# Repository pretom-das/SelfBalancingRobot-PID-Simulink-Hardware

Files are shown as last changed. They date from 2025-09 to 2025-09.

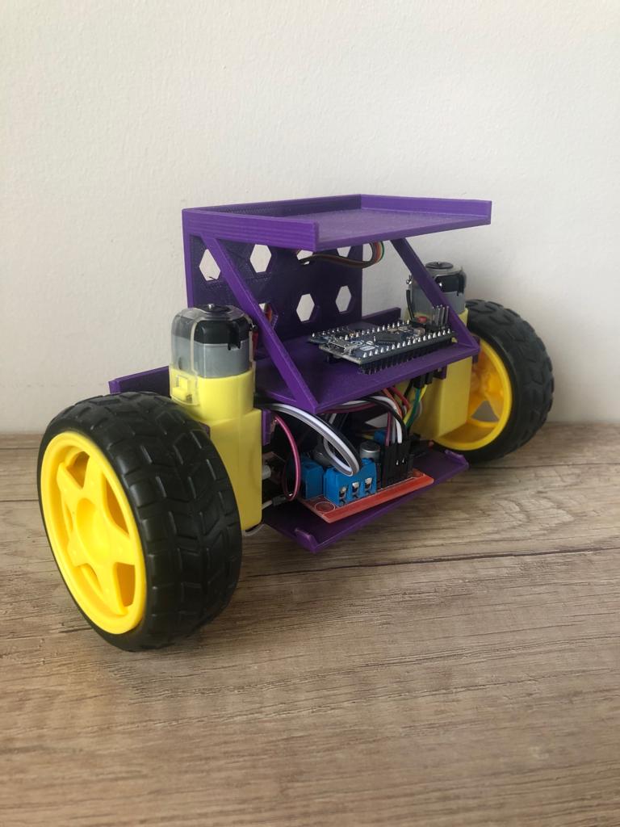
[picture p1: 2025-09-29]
3D print/images/WhatsApp_Image_2019-05-04_at_4.56.32_PM.jpeg

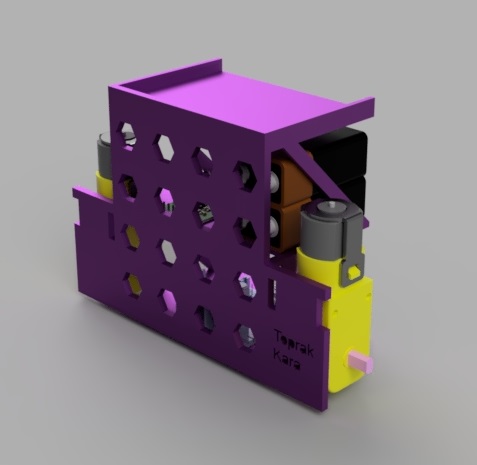
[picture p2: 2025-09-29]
3D print/images/render_back.jpg

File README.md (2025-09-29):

# PID Controlled Self-Balancing Robot

This repository contains all resources for the project:

**"PID Controlled Self-Balancing Robot using MATLAB Simulink and Hardware Implementation: Evaluating Performance under Disturbance"**

---

## 📂 Folder Structure
- `3d-print/` – STL files for chassis, wheels, and mounts.
- `hardware/` – Arduino code for MPU6050, PID controller, motor driver, and OLED HUD.
- `Simulink/` – MATLAB Simulink models and simulation results.
- `papers/` – Research paper (LaTeX + figures).

---

## 🚀 Features
- Real-time balancing using MPU6050 DMP.
- PID controller designed in MATLAB Simulink and validated in hardware.
- OLED HUD for live visualization of angles, PID output, and setpoint.
- STL files for custom 3D-printed chassis and parts.
- Disturbance performance evaluation (push tests, uneven surface, etc.).

---

## 🛠️ Requirements
- MATLAB/Simulink R2021a or later
- Arduino IDE
- MPU6050, L298N, DC motors, SH1106 OLED
- 3D printer for mechanical parts

---

## 📊 Results
- Successfully balanced robot under controlled disturbances.
- Simulink and hardware results compared for validation.

---

---

## Bill of Materials

* Arduino **UNO** (or Nano with same pins)
* **MPU6050** 6-axis IMU (I²C)
* **SH1106** 1.3″ 128×64 OLED (I²C, 0x3C default)
* **L298N** dual H-bridge motor driver
* 2× DC gear motors (left/right)
* Battery pack (recommended **2S Li-ion/LiPo 7.4 V** or **6×AA NiMH 7.2 V**)
* 100–470 µF electrolytic capacitor (across motor supply near L298N)
* Slide switch (battery power)
* Wires, breadboard/headers

> **Power rule:** share **common GND** between UNO, L298N, MPU6050, OLED.

---

## ⚡ Wiring & Power

### I²C Devices (MPU6050 + SH1106 OLED)

| Function  | MPU6050 | SH1106 OLED | UNO Pin |
| --- | --- | --- | --- |
| Power | VCC (3.3–5 V)* | VCC (3.3–5 V)* | **5V** (or 3.3V if required) |
| Ground | GND | GND | **GND** |
| I²C Clock | SCL | SCL | **A5 (SCL)** |
| I²C Data  | SDA | SDA | **A4 (SDA)** |

*Most breakout boards are 5 V-tolerant on I²C; check yours.*

**I²C addresses:**
- MPU6050: `0x68` (AD0=LOW) or `0x69` (AD0=HIGH)
- SH1106: `0x3C` (your sketch uses this)

---

### Motor Driver (L298N) ↔ Arduino

* `ENA → D5 (PWM)`
* `IN1 → D7`, `IN2 → D8`
* `ENB → D6 (PWM)`
* `IN3 → D12`, `IN4 → D13`

| L298N Pin | Connect to |
| --- | --- |
| **ENA** | UNO **D5** (PWM) |
| **IN1** | UNO **D7** |
| **IN2** | UNO **D8** |
| **IN3** | UNO **D12** |
| **IN4** | UNO **D13** |
| **ENB** | UNO **D6** (PWM) |
| **OUT1/OUT2** | Left motor terminals |
| **OUT3/OUT4** | Right motor terminals |
| **12V (V_s)** | Battery **+** (motor supply) |
| **GND** | Battery **−** **and** UNO **GND** (common ground) |
| **5V (on L298N)** | **Do NOT** feed UNO from here. Leave unconnected or remove jumper if present. |

---

### Powering the System

- **UNO logic:** from USB (development) or a 5 V buck converter from the battery.  
- **Motors:** battery → L298N **12V (V_s)**.  
- **Grounds:** UNO **GND** ↔ L298N **GND** ↔ battery **−** ↔ sensor GND.  

**Decoupling:** add a **100–470 µF** electrolytic across **V_s–GND** near the L298N.

## 📄 License
This project is licensed under the MIT License.

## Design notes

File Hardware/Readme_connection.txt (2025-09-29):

Here’s a **ready-to-paste README wiring section** for your self-balancing robot (UNO + MPU6050 + SH1106 + L298N). It matches the pin names in your sketch.

# Wiring & Power

## Bill of Materials

* Arduino **UNO** (or Nano with same pins)
* **MPU6050** 6-axis IMU (I²C)
* **SH1106** 1.3″ 128×64 OLED (I²C, 0x3C default)
* **L298N** dual H-bridge motor driver
* 2× DC gear motors (left/right)
* Battery pack (recommended **2S Li-ion/LiPo 7.4 V** or **6×AA NiMH 7.2 V**)
* 100–470 µF electrolytic cap across motor supply (near L298N)
* Slide switch (battery power)
* Wires, breadboard/headers

> **Power rule:** share **common GND** between UNO, L298N, MPU6050, OLED.

---

## Pin Map (Arduino UNO)

### I²C Devices (MPU6050 + SH1106 OLED)

| Function  | MPU6050 | SH1106 OLED | UNO Pin |
| --- | --- | --- | --- |
| Power | VCC (3.3–5 V)* | VCC (3.3–5 V)* | **5V** (or 3.3V if your modules require) |
| Ground | GND | GND | **GND** |
| I²C Clock | SCL | SCL | **A5 (SCL)** |
| I²C Data  | SDA | SDA | **A4 (SDA)** |

* Most breakout boards are 5 V-tolerant on I²C; check yours. Both modules can run from 3.3 V as well, but keep **both** on the same logic level as the UNO I²C.

**I²C addresses**

* MPU6050: `0x68` (AD0=LOW) or `0x69` (AD0=HIGH)
* SH1106: `0x3C` (your sketch uses this)

---

### Motor Driver (L298N) ↔ Arduino

Your sketch uses:

* `ENA → D5 (PWM)`
* `IN1 → D7`, `IN2 → D8`
* `ENB → D6 (PWM)`
* `IN3 → D12`, `IN4 → D13`

**Connect:**

| L298N Pin | Connect to |
| --- | --- |
| **ENA** | UNO **D5** (PWM) |
| **IN1** | UNO **D7** |
| **IN2** | UNO **D8** |
| **IN3** | UNO **D12** |
| **IN4** | UNO **D13** |
| **ENB** | UNO **D6** (PWM) |
| **OUT1/OUT2** | Left motor terminals |
| **OUT3/OUT4** | Right motor terminals |
| **12V (V_s)** | Battery **+** (motor supply) |
| **GND** | Battery **−** **and** UNO **GND** (common ground) |
| **5V (on L298N)** | **Do NOT** feed UNO from here. Leave unconnected or remove 5 V jumper if present. |

> If your L298N has a **5V-EN** jumper: with **motor V_s ≥ 7 V**, the board’s regulator can power *its own* logic. Still **do not** back-power the UNO from the L298N 5 V pin.

---

### Powering the System

* **UNO logic:** from USB during development, or a clean 5 V regulator (e.g., buck converter from the battery) into **5V** pin.
  *Avoid VIN/barrel jack if your battery is only ~7–8 V; the onboard linear regulator may overheat / drop too much.*
* **Motors:** battery → L298N **12V (V_s)**.
* **Grounds:** connect UNO **GND** ↔ L298N **GND** ↔ battery **−** ↔ sensor GND.

**Decoupling:** place a **100–470 µF** electrolytic across **V_s–GND** at the L298N, plus a **0.1 µF** ceramic near each module (optional but helpful).

---

## Quick Text Schematic (overview)

```
Battery + ------- L298N 12V (V_s)
Battery - -----+-- L298N GND
               | 
               +-- UNO GND --- MPU6050 GND --- OLED GND
UNO 5V  --------- MPU6050 VCC --- OLED VCC
UNO A5 (SCL) ---- MPU6050 SCL --- OLED SCL
UNO A4 (SDA) ---- MPU6050 SDA --- OLED SDA

UNO D5 (PWM) ---- L298N ENA
UNO D7 ---------- L298N IN1
UNO D8 ---------- L298N IN2
UNO D6 (PWM) ---- L298N ENB
UNO D12 --------- L298N IN3
UNO D13 --------- L298N IN4

L298N OUT1/OUT2 -> Left Motor
L298N OUT3/OUT4 -> Right Motor
```

---

## Motor Polarity & Direction

* If wheels spin the **wrong way**, swap a motor’s **OUTx** wires **or** use the code switches:

  * `#define DRIVE_SIGN (-1)` → ensures **negative angle ⇒ wheels go backward** (as requested).
  * If the robot “pushes the fall,” flip sensor signs: `SIGN_PITCH` or `SIGN_GYRO` to `-1`.

---

## First-Power Checklist

1. **Upload code** with robot wheels lifted off the ground.
2. Open Serial Monitor @ **115200** (optional).
3. Verify OLED shows **“Calibrating…”**, then **“Auto-tuning…”** or **“BALANCING”**.
4. Nudge the chassis: angle on OLED should increase for **nose-up**.
5. If motion pushes the robot further over, flip `SIGN_PITCH` or `SIGN_GYRO` (not wiring).
6. If motors just buzz, increase `MOTOR_DEADBAND` (30→40–50) and/or `relay_h` (90→120).

---

## Common Gotchas

* **No common ground** → nothing works reliably.
* **Feeding UNO from L298N 5 V** → brownouts/reset under motor load. Use a separate 5 V regulator for the UNO.
* **Wrong I²C address** → blank OLED. Your code uses `0x3C`. Some SH1106 boards can be `0x3D`.
* **Loose Dupont leads** on ENA/ENB → no PWM control.

---

## Optional: Power Budget Tips

* L298N is lossy; with low-voltage batteries the headroom may be small. If you can, use **higher-torque gear motors** or a more efficient driver (TB6612FNG, BTS7960) later.
* Keep wires short and thick on motor supply; add the bulk cap at L298N.

---

## Testing Sequence

1. **I²C check:** run an I²C scanner; expect `0x68` (MPU) and `0x3C` (OLED).
2. **Sensor sign:** tilt forward/back and watch angle on OLED.
3. **Lifted wheel test:** in **RUN** mode, tilt the robot by hand; wheels should spin to resist.
4. **Floor test:** start near upright, be ready to catch. Use the built-in tilt cut-off (±35°).

---

Copy this into your repo’s `README.md` under a “Wiring & Power” section, and you’re set. If you want, I can add a neat wiring diagram (Fritzing-style PNG/SVG) for the same pinout.

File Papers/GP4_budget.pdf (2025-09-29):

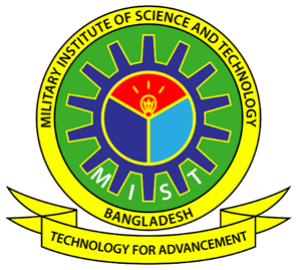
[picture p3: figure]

## Military Institute of Science and Technology

DEPARTMENT OF ELECTRICAL, ELECTRONIC AND COMMUNICATION ENGINEERING

Course Title: Control System Laboratory Course Code: EECE 402
Group: 04

### Project Report

### Robust Control of a Self-Balancing Robot: PID Implementation in MATLAB Simulink and Hardware under Disturbances

Group Information
Name | ID
Minhaj Abedin Siam | 202216063
Pretom Das | 202216072
Sabyasachi Monem | 202216077

Course Instructor:

1. Asst. Prof. Hasan Monir
2. Asst. Prof. Sunjida Sultana
3. Lec Anika Tasnim Tapti
4. Lec Lamiya Mahbub
5. Lec Zia Md Galib Ul Alim

Cost Estimation:

Component | Qty | Unit Price | Price (BDT)
Chassis (3D printed) | 1 | 400 | 400
Yellow DC Geared Motors+ wheel | 2 | 150 | 300
MPU6050 Sensor | 1 | 250 | 250
L298N Motor Driver | 1 | 180 | 180
Arduino UNO | 1 | 1000 | 1000
18650 Li-Ion Battery | 3 | 110 | 330
Battery Case (3-cell) | 1 | 60 | 60
I2C OLED Display | 1 | 680 | 680
Wires box | 1 | 200 | 200
Total | – | | 3400

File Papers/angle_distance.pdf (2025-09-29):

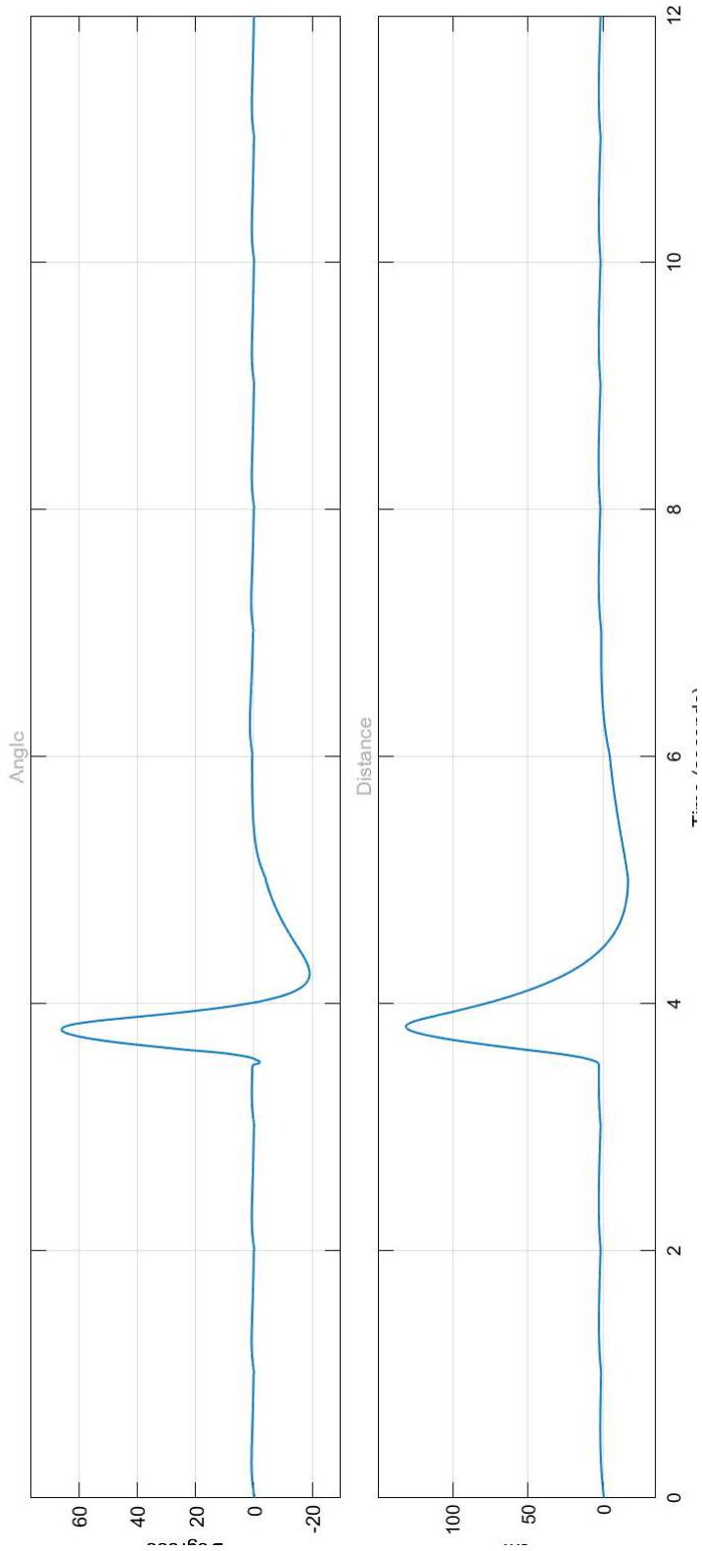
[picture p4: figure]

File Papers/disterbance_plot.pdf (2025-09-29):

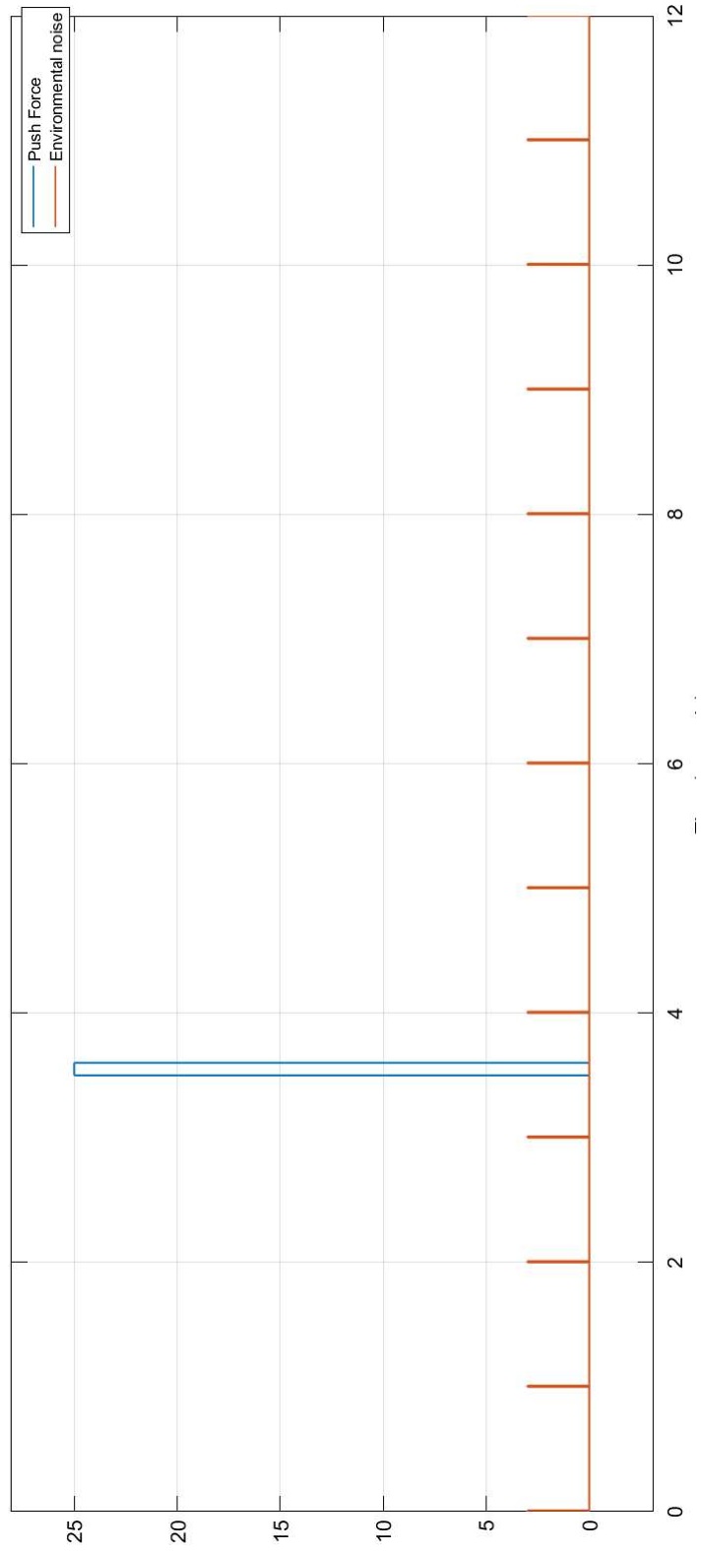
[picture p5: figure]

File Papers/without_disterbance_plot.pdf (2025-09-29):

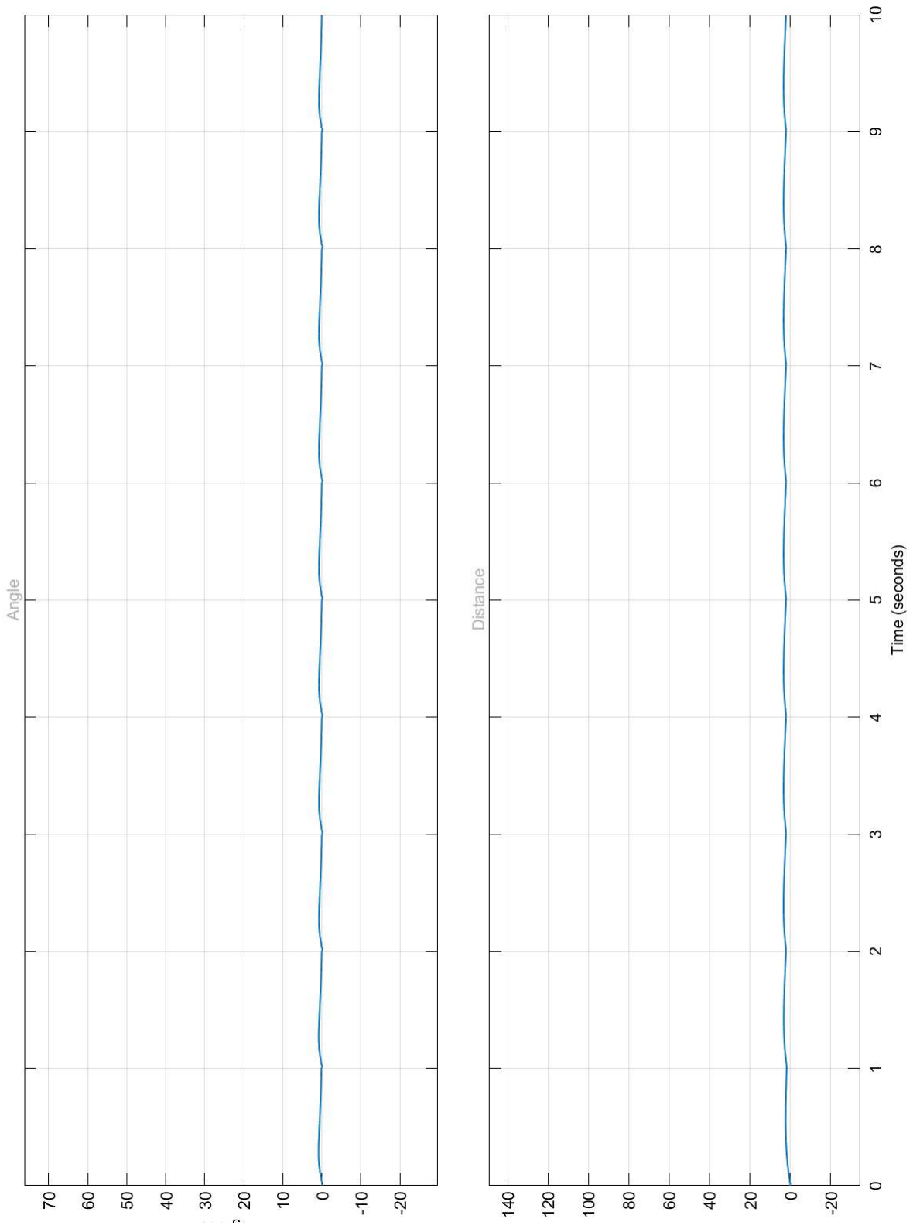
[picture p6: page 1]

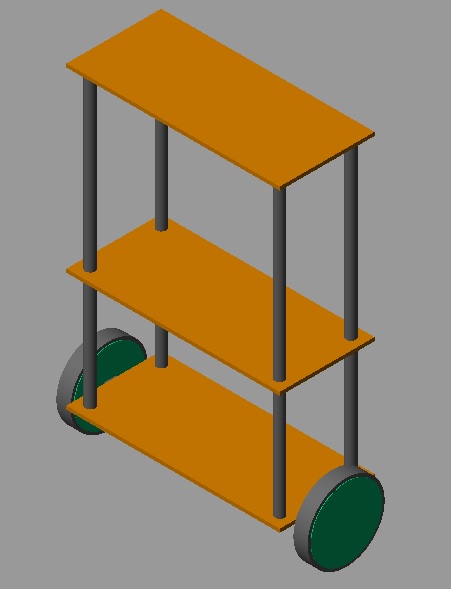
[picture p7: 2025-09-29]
Simulink/img.jpg

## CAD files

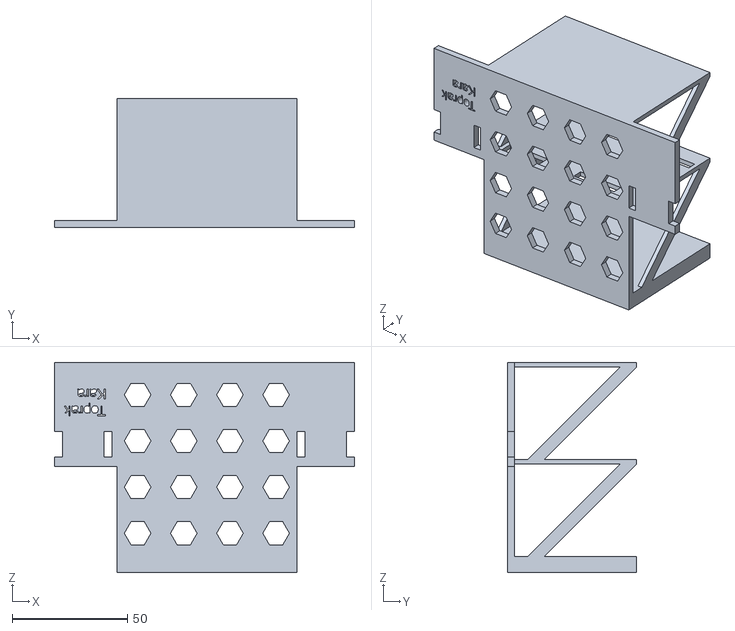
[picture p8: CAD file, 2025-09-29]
3D print/files/main_body_by_tk.stl
130.0 x 56.0 x 91.0

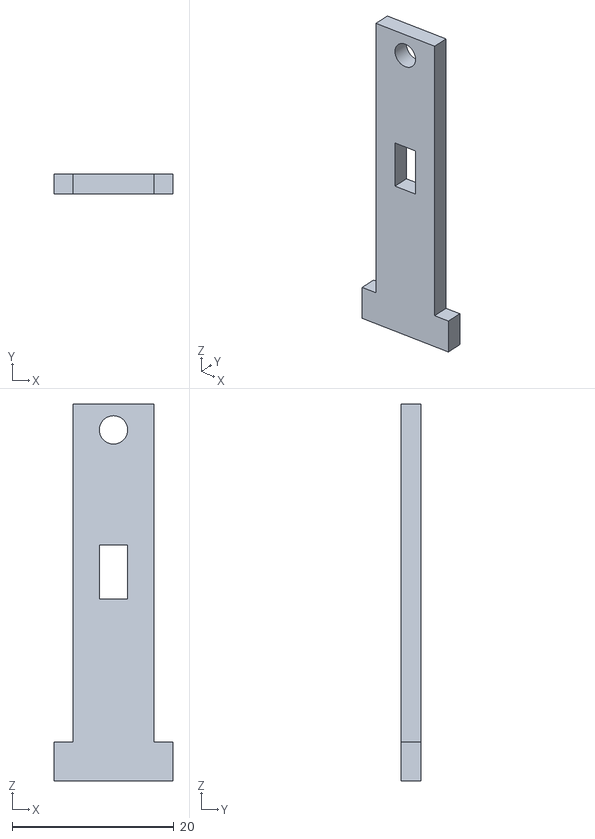
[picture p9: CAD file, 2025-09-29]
3D print/files/motor_maunt.stl
14.7 x 2.50 x 46.6

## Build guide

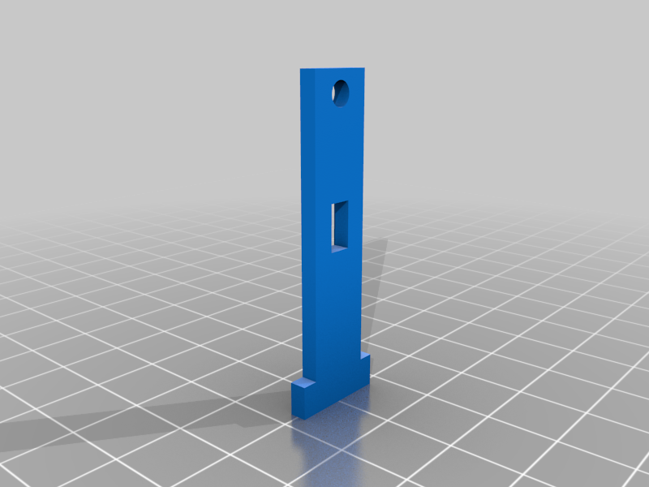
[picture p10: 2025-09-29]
3D print/images/df1292d3a46ace1f10e27a1cf0ae9d68.png

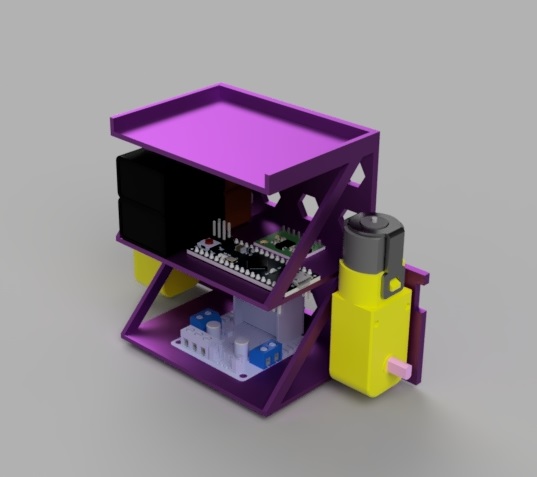
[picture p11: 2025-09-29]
3D print/images/render_1.jpg

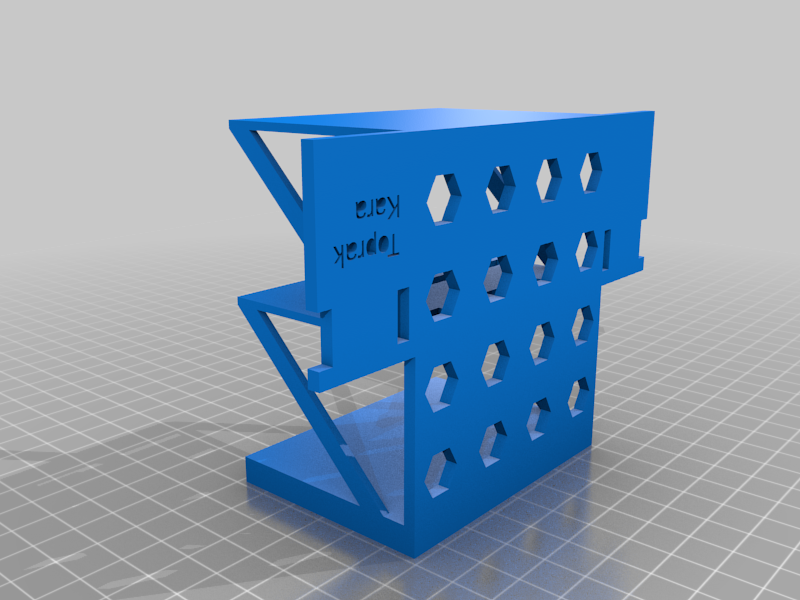
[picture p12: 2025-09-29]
3D print/images/bbad19879211f647a17827d7f1c1ca49.png

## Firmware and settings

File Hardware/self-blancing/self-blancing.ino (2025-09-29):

/*  ---------------------------------------------------------
    SELF-BALANCING ROBOT (UNO + MPU6050 + L298N + 1.3" SH1106 I2C)
    - SH1106 OLED status (I2C)
    - Complementary filter for pitch angle (gyro+accel)
    - Relay auto-tune (Åström–Hägglund) → ZN PID gains
    - EEPROM store/recall of tuned gains
    - L298N dual-motor driver
    - Fixed setpoint (SP_DEG) measured separately
    --------------------------------------------------------- */

#include <Wire.h>
#include <EEPROM.h>
#include <Adafruit_GFX.h>
#include <Adafruit_SH110X.h>
#include <math.h>

// ---------------- OLED (SH1106 128x64 I2C) ----------------
#define OLED_ADDR 0x3C
Adafruit_SH1106G display(128, 64, &Wire, -1);

// ---------------- L298N Pins ----------------
const int ENA = 5;     // PWM
const int IN1 = 7;
const int IN2 = 8;
const int ENB = 6;     // PWM
const int IN3 = 12;
const int IN4 = 13;

// ---------------- Fixed setpoint ------------
const float SP_DEG = 0.0f;  // <<< REPLACE with your measured upright angle (deg)

// ---------------- MPU6050 -------------------
const uint8_t MPU_ADDR = 0x68;   // AD0 low
const float GYRO_SENS = 131.0f;  // LSB/(°/s) @ ±250 dps
const float ACC_SENS  = 16384.0f;// LSB/g @ ±2g

float gyroX_off=0, gyroY_off=0, gyroZ_off=0;
float accX_off=0,  accY_off=0,  accZ_off=0;

// ------------- Complementary Filter ---------
float pitch_deg = 0.0f;
float alpha = 0.98f;             // gyro weight
unsigned long lastMicros = 0;
float loop_dt = 0.005f;          // seconds, updated each loop

// ---------------- PID -----------------------
volatile float setpoint = SP_DEG;     // fixed upright
float Kp = 18.0f, Ki = 0.0f, Kd = 0.6f; // defaults if no EEPROM
float i_term = 0.0f, prev_err = 0.0f;
float out_min = -255, out_max = 255;

// ------------- Auto-tune (relay) ------------
enum Mode { MODE_AUTOTUNE, MODE_RUN } mode = MODE_AUTOTUNE;
const float relay_h = 80.0f;          // PWM magnitude for relay drive (tweak 60–120)
const float tune_window = 2.0f;       // deg hysteresis around setpoint
const unsigned long settle_ms = 3000; // let oscillation stabilize
float max_angle = -1e9, min_angle = 1e9;
unsigned long last_cross_ms = 0;
unsigned long period_ms = 0;
int cross_count = 0;
bool settled = false;

// --------------- EEPROM ---------------------
struct Gains { float Kp, Ki, Kd; uint32_t magic; };
const uint32_t MAGIC = 0xBABA00F1;
const int EE_ADDR = 0;

// --------------- Utils ----------------------
float constrainf(float x, float a, float b){ return x<a? a : (x>b? b : x); }

// --------------- I2C helpers ----------------
void mpuWrite(uint8_t reg, uint8_t val){
  Wire.beginTransmission(MPU_ADDR); Wire.write(reg); Wire.write(val); Wire.endTransmission();
}
void mpuRead(uint8_t reg, uint8_t* buf, uint8_t len){
  Wire.beginTransmission(MPU_ADDR); Wire.write(reg); Wire.endTransmission(false);
  Wire.requestFrom(MPU_ADDR, len, true);
  for(uint8_t i=0;i<len && Wire.available();++i) buf[i]=Wire.read();
}

// --------------- MPU init -------------------
void mpuInit(){
  mpuWrite(0x6B, 0x00);   // PWR_MGMT_1: wake
  mpuWrite(0x1B, 0x00);   // GYRO_CONFIG: ±250 dps
  mpuWrite(0x1C, 0x00);   // ACCEL_CONFIG: ±2g
  delay(100);
}

// Keep robot still during this (~1s)
void mpuCalibrate(){
  const int N=1000;
  long gx=0, gy=0, gz=0, ax=0, ay=0, az=0;
  uint8_t raw[14];
  for(int i=0;i<N;i++){
    mpuRead(0x3B, raw, 14);
    int16_t axr = (raw[0]<<8)|raw[1];
    int16_t ayr = (raw[2]<<8)|raw[3];
    int16_t azr = (raw[4]<<8)|raw[5];
    int16_t gxr = (raw[8]<<8)|raw[9];
    int16_t gyr = (raw[10]<<8)|raw[11];
    int16_t gzr = (raw[12]<<8)|raw[13];
    ax += axr; ay += ayr; az += azr;
    gx += gxr; gy += gyr; gz += gzr;
    delay(1);
  }
  accX_off = (float)ax/N;
  accY_off = (float)ay/N;
  accZ_off = (float)az/N - ACC_SENS; // ~+1g on Z
  gyroX_off= (float)gx/N;
  gyroY_off= (float)gy/N;
  gyroZ_off= (float)gz/N;
}

// --------------- Sensor + angle -------------
void updateAngle(){
  uint8_t raw[14];
  mpuRead(0x3B, raw, 14);
  int16_t axr = (raw[0]<<8)|raw[1];
  int16_t ayr = (raw[2]<<8)|raw[3];
  int16_t azr = (raw[4]<<8)|raw[5];
  int16_t gyr = (raw[10]<<8)|raw[11];

  float axg = (axr - accX_off)/ACC_SENS;
  float ayg = (ayr - accY_off)/ACC_SENS;
  float azg = (azr - accZ_off)/ACC_SENS;

  // Pitch from accel (degrees). Assume X forward, Y left, Z up
  float accPitch = atan2f(axg, sqrtf(ayg*ayg + azg*azg)) * 180.0f/PI;
  float gyroY_dps = (gyr - gyroY_off)/GYRO_SENS;

  unsigned long now = micros();
  float dt = (lastMicros==0) ? 0.005f : (now - lastMicros)*1e-6f;
  if (dt < 0.0005f) dt = 0.0005f; // clamp to tame spikes
  if (dt > 0.02f)   dt = 0.02f;
  lastMicros = now;
  loop_dt = dt;

  // Complementary filter
  pitch_deg = alpha*(pitch_deg + gyroY_dps*dt) + (1.0f - alpha)*accPitch;
}

// --------------- Motors (L298N) -------------
void setMotorPWM(float u){
  // u in [-255, 255]
  int pwm = (int)fabs(u);
  pwm = constrain(pwm, 0, 255);

  if (u >= 0){
    // forward
    digitalWrite(IN1, HIGH); digitalWrite(IN2, LOW);
    digitalWrite(IN3, HIGH); digitalWrite(IN4, LOW);
  } else {
    // backward
    digitalWrite(IN1, LOW); digitalWrite(IN2, HIGH);
    digitalWrite(IN3, LOW); digitalWrite(IN4, HIGH);
  }

  // Overcome friction deadband
  if (pwm > 0 && pwm < 30) pwm = 30;

  analogWrite(ENA, pwm);
  analogWrite(ENB, pwm);
}

// ---------------- PID (time-based) ----------
float pidCompute(float angle){
  // continuous-time ZN gains
  static float d_filt = 0.0f;       // filtered derivative
  const float tau_d = 0.02f;         // derivative low-pass (~20 ms)
  const float dt = loop_dt;

  float err = setpoint - angle;

  // integral with anti-windup
  i_term += Ki * err * dt;
  i_term = constrainf(i_term, -300.0f, 300.0f);

  // derivative
  float derr = (err - prev_err) / (dt > 1e-6f ? dt : 1e-6f);
  float alpha_d = tau_d / (tau_d + dt);
  d_filt = alpha_d * d_filt + (1.0f - alpha_d) * derr;

  float u = Kp * err + i_term + Kd * d_filt;
  prev_err = err;
  return constrainf(u, out_min, out_max);
}

// ----- Auto-tune helpers & step function ----
void resetAutotuneState(){
  max_angle = -1e9; min_angle = 1e9;
  last_cross_ms = 0;
  period_ms = 0;
  cross_count = 0;
  settled = false;
}

bool autotuneStep(){
  float err = setpoint - pitch_deg;

  // Relay with hysteresis to avoid chatter
  static int state = 0; // -1 or +1
  if (state == 0) state = (err >= 0) ? +1 : -1;
  if (state == +1 && err < -tune_window) state = -1;
  if (state == -1 && err > +tune_window) state = +1;

  float u = (state >= 0) ? +relay_h : -relay_h;
  setMotorPWM(u);

  // Allow settling
  static unsigned long start_ms = millis();
  if (!settled && (millis() - start_ms) > settle_ms){
    settled = true;
    last_cross_ms = millis();
  }
  if (!settled) return false;

  // Track peaks within half-cycles
  if (pitch_deg > max_angle) max_angle = pitch_deg;
  if (pitch_deg < min_angle) min_angle = pitch_deg;

  // Detect state change = half-period
  static int last_state = state;
  if (state != last_state){
    unsigned long now = millis();
    unsigned long half_period = now - last_cross_ms;
    last_cross_ms = now;
    last_state = state;
    cross_count++;

    if (cross_count >= 4){ // enough samples
      period_ms = 2 * half_period; // ~full Pu
      float a = 0.5f * (max_angle - min_angle);
      if (a < 0.5f) a = 0.5f; // avoid tiny amplitude

      float Ku = (4.0f * relay_h) / (PI * a);
      float Pu = period_ms / 1000.0f;

      // Ziegler–Nichols PID (classic)
      float newKp = 0.6f * Ku;
      float newKi = 2.0f * newKp / Pu;
      float newKd = newKp * Pu / 8.0f;

      if (isfinite(newKp) && isfinite(newKi) && isfinite(newKd) &&
          newKp>0 && newKi>=0 && newKd>=0 && Pu>0.05f && Pu<5.0f){
        Kp = constrainf(newKp, 1.0f, 120.0f);
        Ki = constrainf(newKi, 0.0f, 500.0f);
        Kd = constrainf(newKd, 0.0f, 60.0f);
        Gains g{Kp,Ki,Kd,MAGIC};
        EEPROM.put(EE_ADDR, g);
        return true; // tuning done
      } else {
        // retry: reset peaks/counter
        max_angle = -1e9; min_angle = 1e9; cross_count = 0;
      }
    }
    // reset peaks for next half-cycle
    max_angle = -1e9; min_angle = 1e9;
  }
  return false;
}

// ---------------- OLED HUD ------------------
void drawOLED(const char* top){
  display.clearDisplay();
  display.setTextColor(SH110X_WHITE);

  display.setTextSize(1);
  display.setCursor(0,0);
  display.print(top);

  display.setCursor(0,14);
  display.print("Ang: "); display.print(pitch_deg,1); display.print(" deg");

  display.setCursor(0,28);
  display.print("Kp: "); display.print(Kp,1);
  display.setCursor(64,28);
  display.print("Ki: "); display.print(Ki,1);

  display.setCursor(0,42);
  display.print("Kd: "); display.print(Kd,1);

  display.setCursor(0,56);
  display.print("SP: "); display.print(setpoint,1);

  // simple balance bar
  int cx=100, cy=40, w=24, h=8;
  display.drawRect(cx, cy, w, h, SH110X_WHITE);
  float p = constrainf((pitch_deg+15.0f)/30.0f, 0.0f, 1.0f);
  int filled = (int)(p*(w-2));
  display.fillRect(cx+1, cy+1, filled, h-2, SH110X_WHITE);

  display.display();
}

// ---------------- Setup ---------------------
void setup(){
  pinMode(IN1, OUTPUT); pinMode(IN2, OUTPUT);
  pinMode(IN3, OUTPUT); pinMode(IN4, OUTPUT);
  pinMode(ENA, OUTPUT); pinMode(ENB, OUTPUT);
  analogWrite(ENA, 0); analogWrite(ENB, 0);

  Wire.begin();             // UNO: SDA=A4, SCL=A5
  Wire.setClock(100000);    // keep slow & stable
  mpuInit();

  if (!display.begin(OLED_ADDR, true)) { /* if needed, try 0x3D */ }
  display.clearDisplay(); display.display();

  // Load saved gains if present
  Gains g; EEPROM.get(EE_ADDR, g);
  if (g.magic == MAGIC && isfinite(g.Kp) && isfinite(g.Ki) && isfinite(g.Kd)){
    Kp=g.Kp; Ki=g.Ki; Kd=g.Kd; mode = MODE_RUN;
  } else {
    mode = MODE_AUTOTUNE;
  }

  drawOLED("Calibrating...");
  mpuCalibrate();           // keep robot still
  lastMicros = micros();

  Serial.begin(115200);
}

// ---------------- Loop ----------------------
void loop(){
  updateAngle();

  // Tilt safety cutout (prevents thrashing when it falls)
  if (fabs(pitch_deg) > 35.0f) {
    i_term = 0; prev_err = 0;
    setMotorPWM(0);
    drawOLED("TILT SAFETY");
    delay(10);
    return;
  }

  if (mode == MODE_AUTOTUNE){
    bool done = autotuneStep();
    drawOLED("Auto-tuning...");
    if (done){
      setMotorPWM(0);
      delay(500);
      i_term=0; prev_err=0;
      mode = MODE_RUN;
      drawOLED("Tuned & saved");
      delay(400);
    }
  } else { // MODE_RUN
    float u = pidCompute(pitch_deg);
    setMotorPWM(u);
    drawOLED("BALANCING");
  }
}

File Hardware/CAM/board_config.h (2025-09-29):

#define PWDN_GPIO_NUM     32
#define RESET_GPIO_NUM    -1
#define XCLK_GPIO_NUM     0
#define SIOD_GPIO_NUM     26
#define SIOC_GPIO_NUM     27

#define Y9_GPIO_NUM       35
#define Y8_GPIO_NUM       34
#define Y7_GPIO_NUM       39
#define Y6_GPIO_NUM       36
#define Y5_GPIO_NUM       21
#define Y4_GPIO_NUM       19
#define Y3_GPIO_NUM       18
#define Y2_GPIO_NUM       5
#define VSYNC_GPIO_NUM    25
#define HREF_GPIO_NUM     23
#define PCLK_GPIO_NUM     22

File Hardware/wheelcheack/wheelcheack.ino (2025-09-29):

/* ---------------------------------------------------------
   INTERACTIVE MOTOR JOG (UNO + L298N)
   Pins (same as your project):
     RIGHT: ENA=5 (PWM), IN1=7, IN2=8   -> OUT1/OUT2
     LEFT : ENB=6 (PWM), IN3=12, IN4=13 -> OUT3/OUT4

   Serial @ 115200. Commands (case-insensitive):
     RF [p]  -> Right  Forward  with optional PWM (0..255)
     RB [p]  -> Right  Backward
     RC      -> Right  Coast (freewheel)
     RK      -> Right  Brake (short brake)

     LF [p]  -> Left   Forward
     LB [p]  -> Left   Backward
     LC      -> Left   Coast
     LK      -> Left   Brake

     AF [p]  -> BOTH Forward
     AB [p]  -> BOTH Backward
     AC      -> BOTH Coast
     AK      -> BOTH Brake

     P [p]   -> Set default PWM (used when cmd has no [p])
     + / -   -> Increase / decrease default PWM by 10
     ?       -> Help
     X       -> All stop (brake)
   Examples:
     RF 180   (right fwd at 180)
     LB       (left back at default PWM)
     AK       (both brake)
     P 200    (set default PWM = 200)
--------------------------------------------------------- */

#include <Arduino.h>

// ---- Pins
const int ENA = 5;     // RIGHT PWM
const int IN1 = 7;
const int IN2 = 8;
const int ENB = 6;     // LEFT PWM
const int IN3 = 12;
const int IN4 = 13;

// ---- Defaults
int defaultPWM = 180;    // used if command omits [p]
int deadband   = 30;     // minimum kick to overcome friction (applied when pwm>0)

// ---- Helpers
void rightDrive(int dir, int pwm) {
  pwm = constrain(pwm, 0, 255);
  if (dir > 0)      { digitalWrite(IN1, HIGH); digitalWrite(IN2, LOW);  }
  else if (dir < 0) { digitalWrite(IN1, LOW);  digitalWrite(IN2, HIGH); }
  else              { digitalWrite(IN1, LOW);  digitalWrite(IN2, LOW);  } // coast
  if (pwm > 0 && pwm < deadband) pwm = deadband;
  analogWrite(ENA, pwm);
}
void leftDrive(int dir, int pwm) {
  pwm = constrain(pwm, 0, 255);
  if (dir > 0)      { digitalWrite(IN3, HIGH); digitalWrite(IN4, LOW);  }
  else if (dir < 0) { digitalWrite(IN3, LOW);  digitalWrite(IN4, HIGH); }
  else              { digitalWrite(IN3, LOW);  digitalWrite(IN4, LOW);  } // coast
  if (pwm > 0 && pwm < deadband) pwm = deadband;
  analogWrite(ENB, pwm);
}
void rightBrake(){ digitalWrite(IN1, HIGH); digitalWrite(IN2, HIGH); analogWrite(ENA, 0); }
void leftBrake() { digitalWrite(IN3, HIGH); digitalWrite(IN4, HIGH); analogWrite(ENB, 0); }

void allStopBrake(){ rightBrake(); leftBrake(); }
void allCoast()    { rightDrive(0,0); leftDrive(0,0); }

void printHUD(const char* msg){
  Serial.print(F("[PWM=")); Serial.print(defaultPWM);
  Serial.print(F(", dead=")); Serial.print(deadband);
  Serial.print(F("]  "));
  Serial.println(msg);
}

void help(){
  Serial.println(F("\nCommands:"));
  Serial.println(F("  RF [p], RB [p], RC, RK   -> Right motor Fwd/Back/Coast/Brake"));
  Serial.println(F("  LF [p], LB [p], LC, LK   -> Left  motor Fwd/Back/Coast/Brake"));
  Serial.println(F("  AF [p], AB [p], AC, AK   -> BOTH  motors Fwd/Back/Coast/Brake"));
  Serial.println(F("  P [p]    -> set default PWM (0..255)"));
  Serial.println(F("  + / -    -> inc/dec default PWM by 10"));
  Serial.println(F("  D [v]    -> set deadband (0..80), applied when pwm>0"));
  Serial.println(F("  X        -> ALL STOP (brake)"));
  Serial.println(F("  ?        -> this help\n"));
}

// Trim spaces and uppercase
String cleanUpper(String s){
  s.trim();
  for (unsigned i=0;i<s.length();++i) s[i] = toupper(s[i]);
  return s;
}

// Parse optional integer after a command (e.g., 'RF 180')
bool parseIntAfter(const String& s, int& outVal){
  // find first space
  int sp = s.indexOf(' ');
  if (sp < 0) return false;
  String t = s.substring(sp+1);
  t.trim();
  if (t.length()==0) return false;
  outVal = t.toInt();
  return true;
}

void setup(){
  pinMode(IN1, OUTPUT); pinMode(IN2, OUTPUT);
  pinMode(IN3, OUTPUT); pinMode(IN4, OUTPUT);
  pinMode(ENA, OUTPUT); pinMode(ENB, OUTPUT);

  allCoast();

  Serial.begin(115200);
  delay(300);
  Serial.println(F("\n=== INTERACTIVE MOTOR JOG ==="));
  Serial.println(F("Type '?' for help. Place robot on a stand!"));
  printHUD("Ready.");
}

void loop(){
  // quick +/- shortcuts without newline
  if (Serial.available()){
    // Peek: if single-char control, handle directly
    int c = Serial.peek();
    if (c=='+' || c=='-'){
      Serial.read();
      defaultPWM = constrain(defaultPWM + (c=='+'? +10 : -10), 0, 255);
      printHUD(c=='+' ? "PWM +10" : "PWM -10");
      return;
    }
  }

  if (Serial.available()){
    String line = Serial.readStringUntil('\n');
    line = cleanUpper(line);
    if (line.length()==0) return;

    // single-char commands
    if (line=="X"){ allStopBrake(); printHUD("ALL STOP (brake)"); return; }
    if (line=="?"){ help(); printHUD("OK"); return; }

    // deadband set: D [v]
    if (line.startsWith("D")){
      int v;
      if (parseIntAfter(line, v)){
        deadband = constrain(v, 0, 80);
        printHUD("Deadband set");
      } else {
        Serial.println(F("Usage: D 30   (0..80)"));
      }
      return;
    }

    // PWM set: P [p]
    if (line.startsWith("P")){
      int p;
      if (parseIntAfter(line, p)){
        defaultPWM = constrain(p, 0, 255);
        printHUD("Default PWM set");
      } else {
        Serial.println(F("Usage: P 200   (0..255)"));
      }
      return;
    }

    // Motor commands
    // Pattern: [R|L|A][F|B|C|K] [p]
    if (line.length() >= 2){
      char side = line[0];
      char act  = line[1];
      int p; bool hasP = parseIntAfter(line, p);
      int pwm = hasP ? constrain(p,0,255) : defaultPWM;
      if (pwm>0 && pwm<deadband) pwm = deadband;

      auto doSide = [&](char s, char a){
        if (s=='R'){
          if (a=='F') { rightDrive(+1, pwm); printHUD("Right FORWARD"); }
          else if (a=='B') { rightDrive(-1, pwm); printHUD("Right BACKWARD"); }
          else if (a=='C') { rightDrive(0, 0);    printHUD("Right COAST"); }
          else if (a=='K') { rightBrake();        printHUD("Right BRAKE"); }
          else { Serial.println(F("Unknown action. Use F/B/C/K.")); }
        } else if (s=='L'){
          if (a=='F') { leftDrive(+1, pwm); printHUD("Left FORWARD"); }
          else if (a=='B') { leftDrive(-1, pwm); printHUD("Left BACKWARD"); }
          else if (a=='C') { leftDrive(0, 0);    printHUD("Left COAST"); }
          else if (a=='K') { leftBrake();        printHUD("Left BRAKE"); }
          else { Serial.println(F("Unknown action. Use F/B/C/K.")); }
        } else if (s=='A'){
          if (a=='F') { rightDrive(+1, pwm); leftDrive(+1, pwm); printHUD("Both FORWARD"); }
          else if (a=='B') { rightDrive(-1, pwm); leftDrive(-1, pwm); printHUD("Both BACKWARD"); }
          else if (a=='C') { allCoast();   printHUD("Both COAST"); }
          else if (a=='K') { allStopBrake(); printHUD("Both BRAKE"); }
          else { Serial.println(F("Unknown action. Use F/B/C/K.")); }
        } else {
          Serial.println(F("Unknown side. Use R/L/A."));
        }
      };
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
